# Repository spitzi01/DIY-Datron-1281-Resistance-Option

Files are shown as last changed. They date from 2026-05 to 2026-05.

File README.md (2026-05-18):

# DIY-Datron-1281-Resistance-Option
Add resistance measurement capabilities to your Datron 1281

I also replicated the resistance measurement board as closely as I could. This was a lot harder than the current board. Most of the parts are still avaiable. The CLA3106 ASIC can be replaced with my CPLD replacement. For other unavaiable components I tried to find alternatives. The precision resistors are the most expensive part of this project, but there is no real other choice than Vishay foil resistors and there are quite a few. There are also two resistance standards on this PCB. These are importeant for the selftest and the selfcal capability of this meter. For this purpose I ordered VHP resistors. The resistors for the current ranges are mostly custom ordered from Texas Components. The PCB features full mechanical compatibility to the original board and all guard traces.

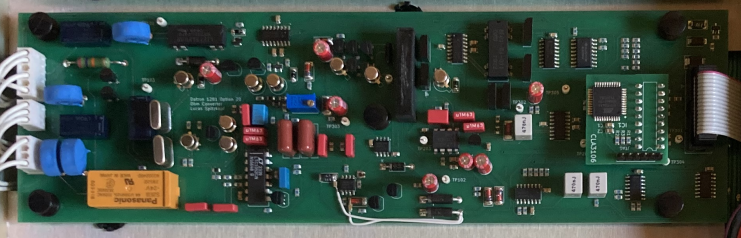
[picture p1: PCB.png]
DIY Resistance Option in Datron 1281


A full characterization of the resistance option was not possible due to not having access the known standard resistors. I did a comparative measurement in the 10kOhm range with a short against my Solartron 7081. The noise is definitly comparable to the Solartron meter. At the moment I will see this as a win until I am able to perform better measurements.

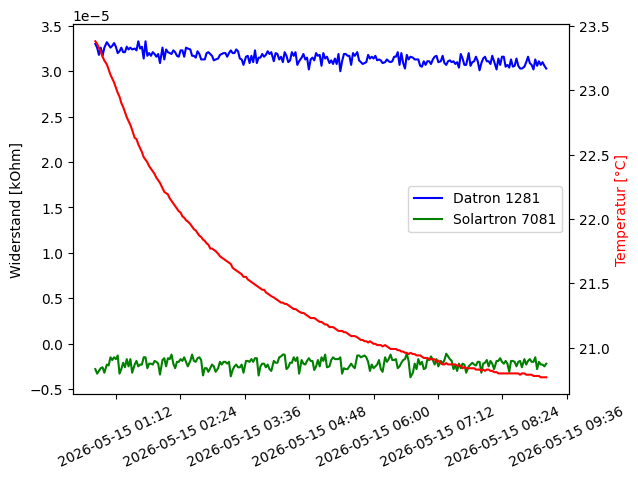
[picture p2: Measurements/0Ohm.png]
Noise and stability of the 10kOhm range


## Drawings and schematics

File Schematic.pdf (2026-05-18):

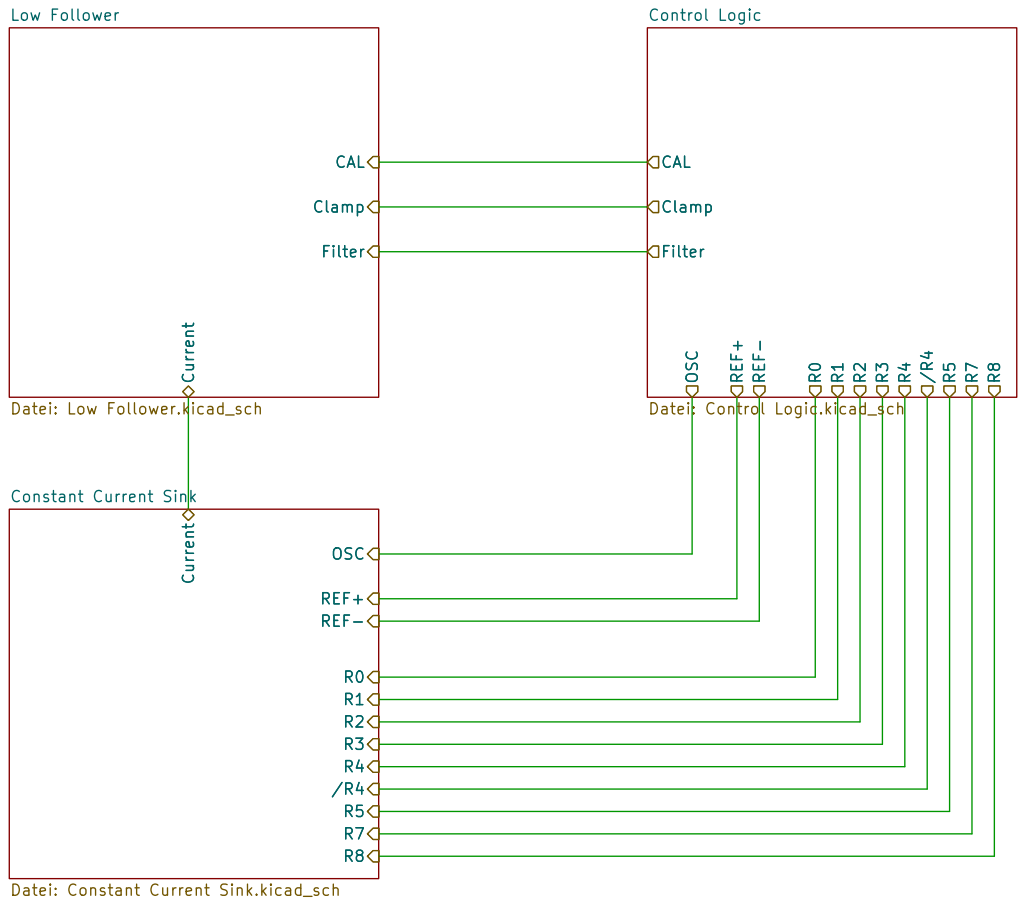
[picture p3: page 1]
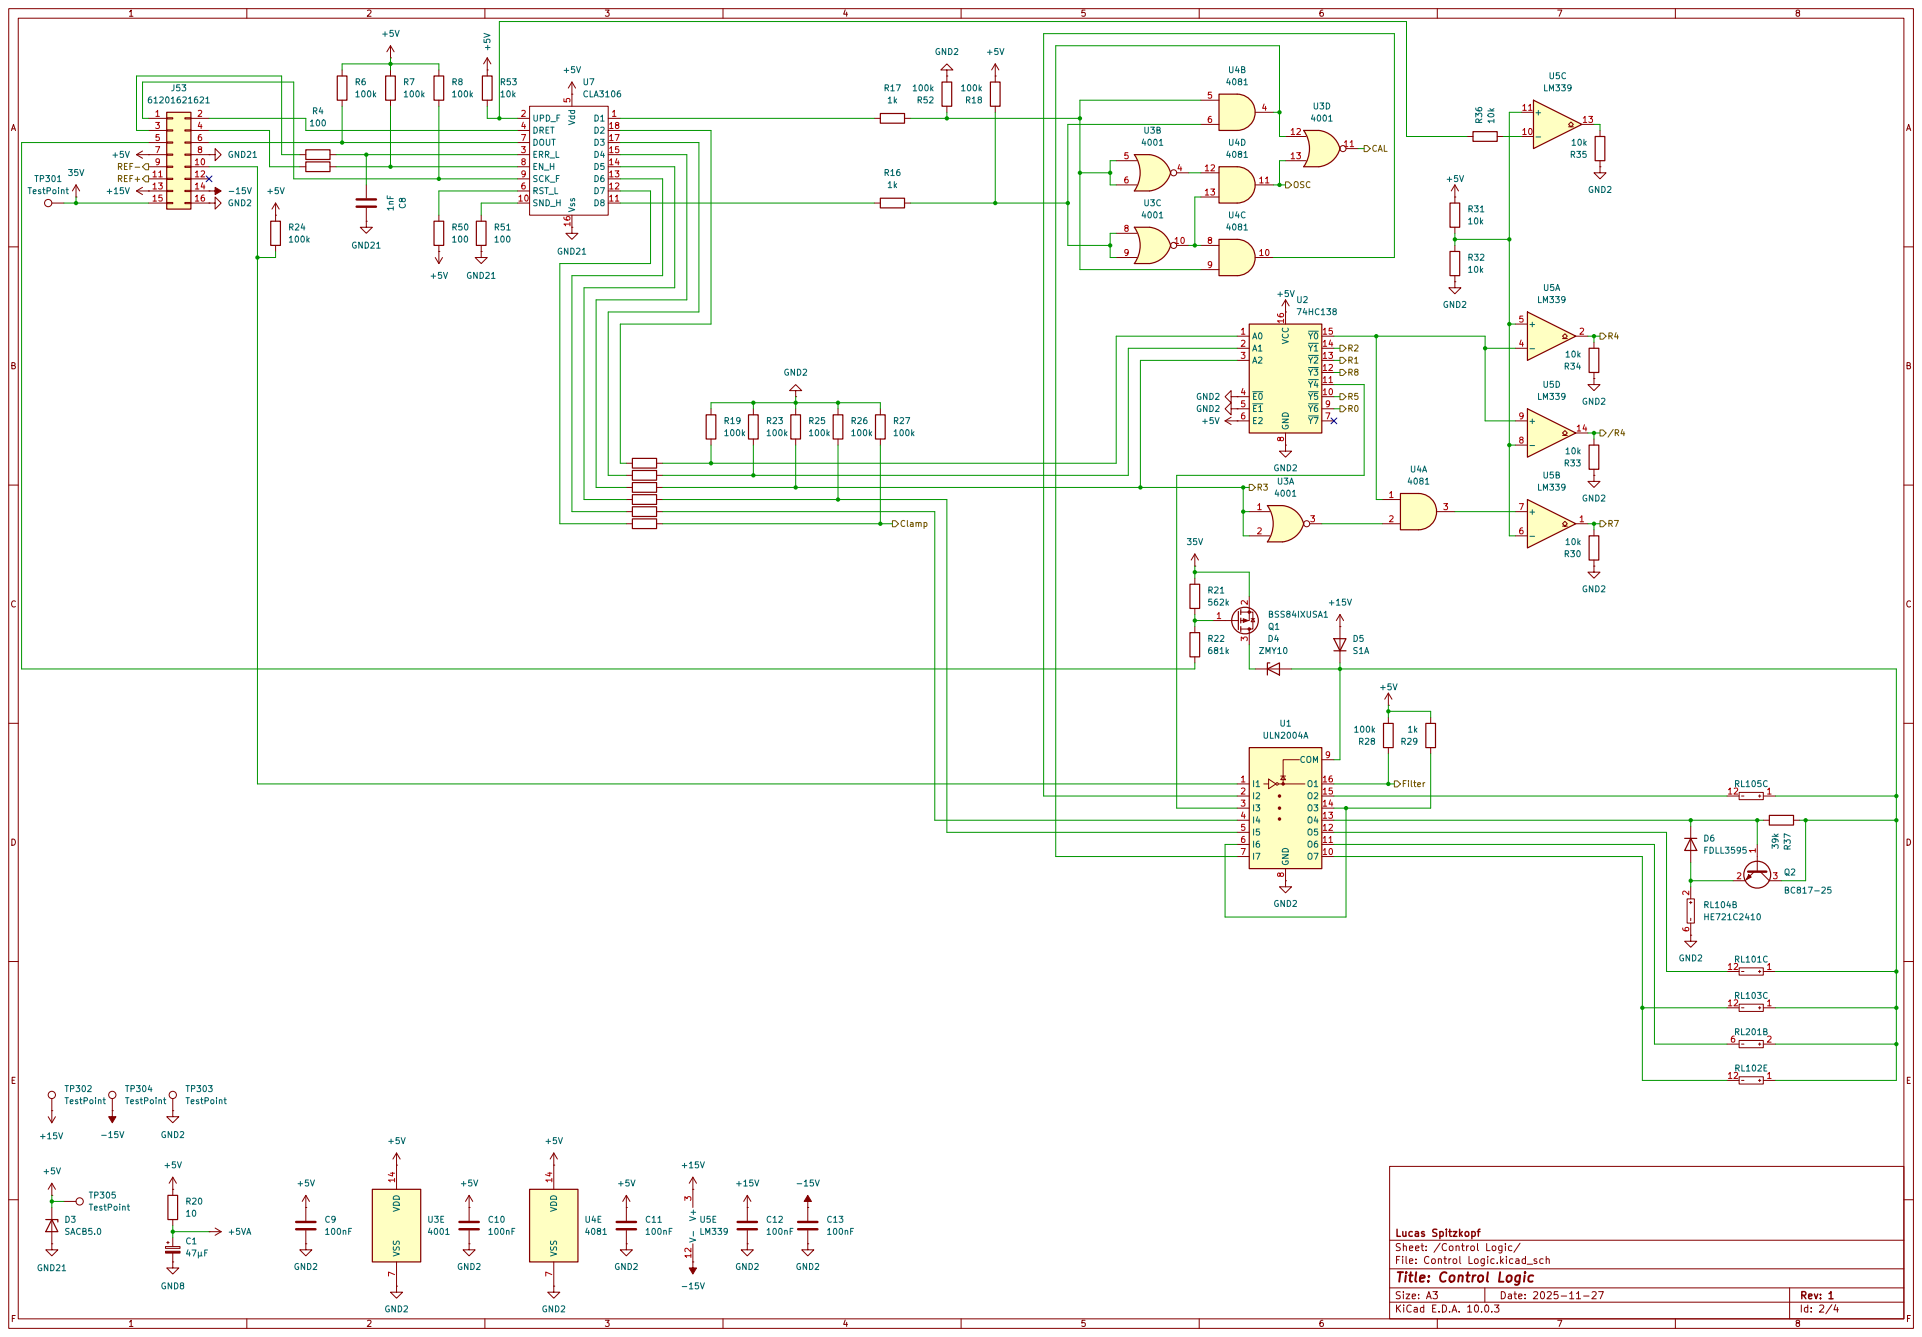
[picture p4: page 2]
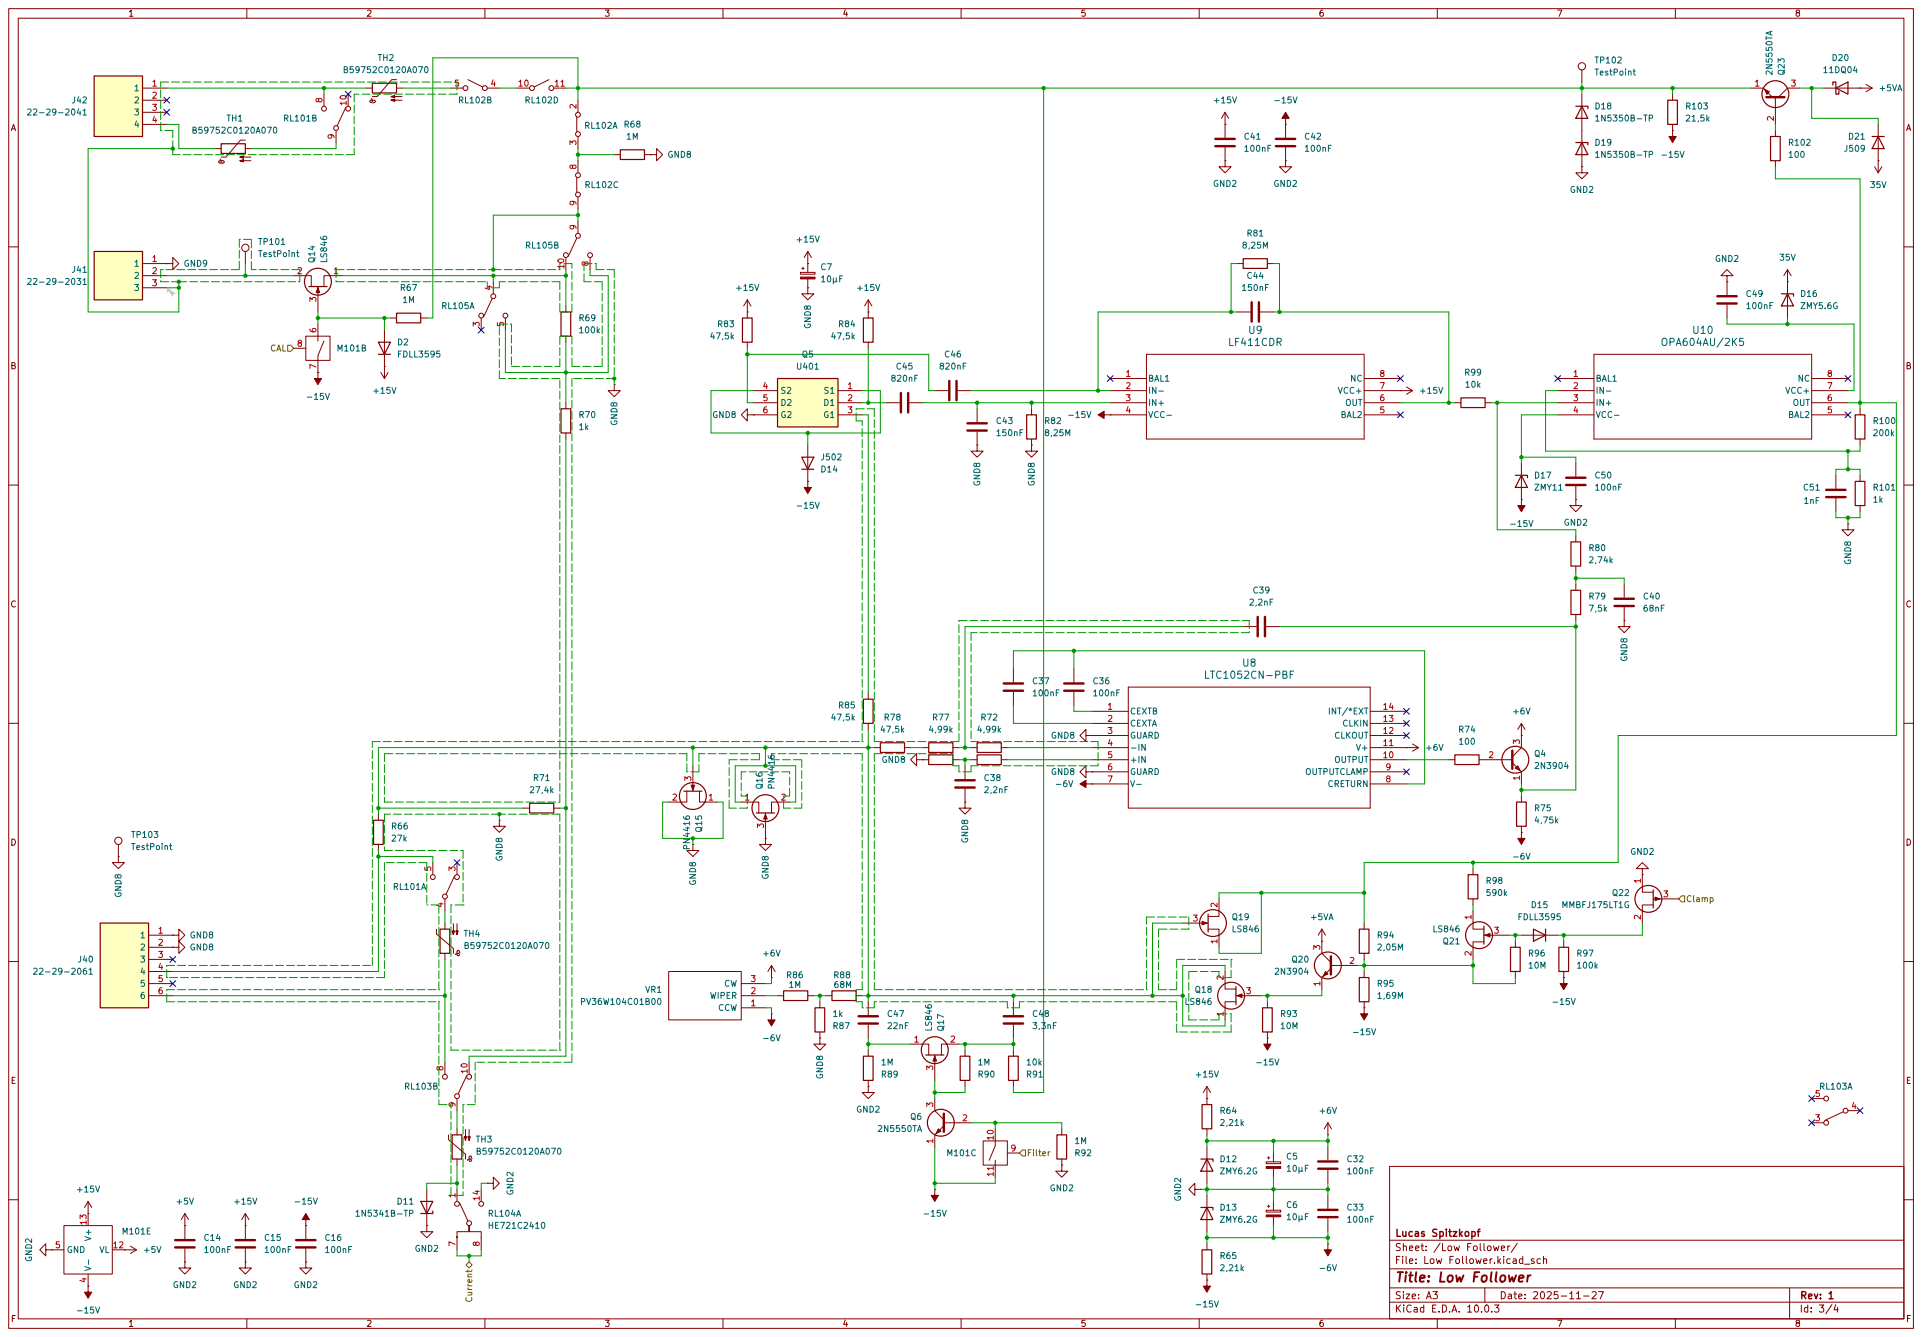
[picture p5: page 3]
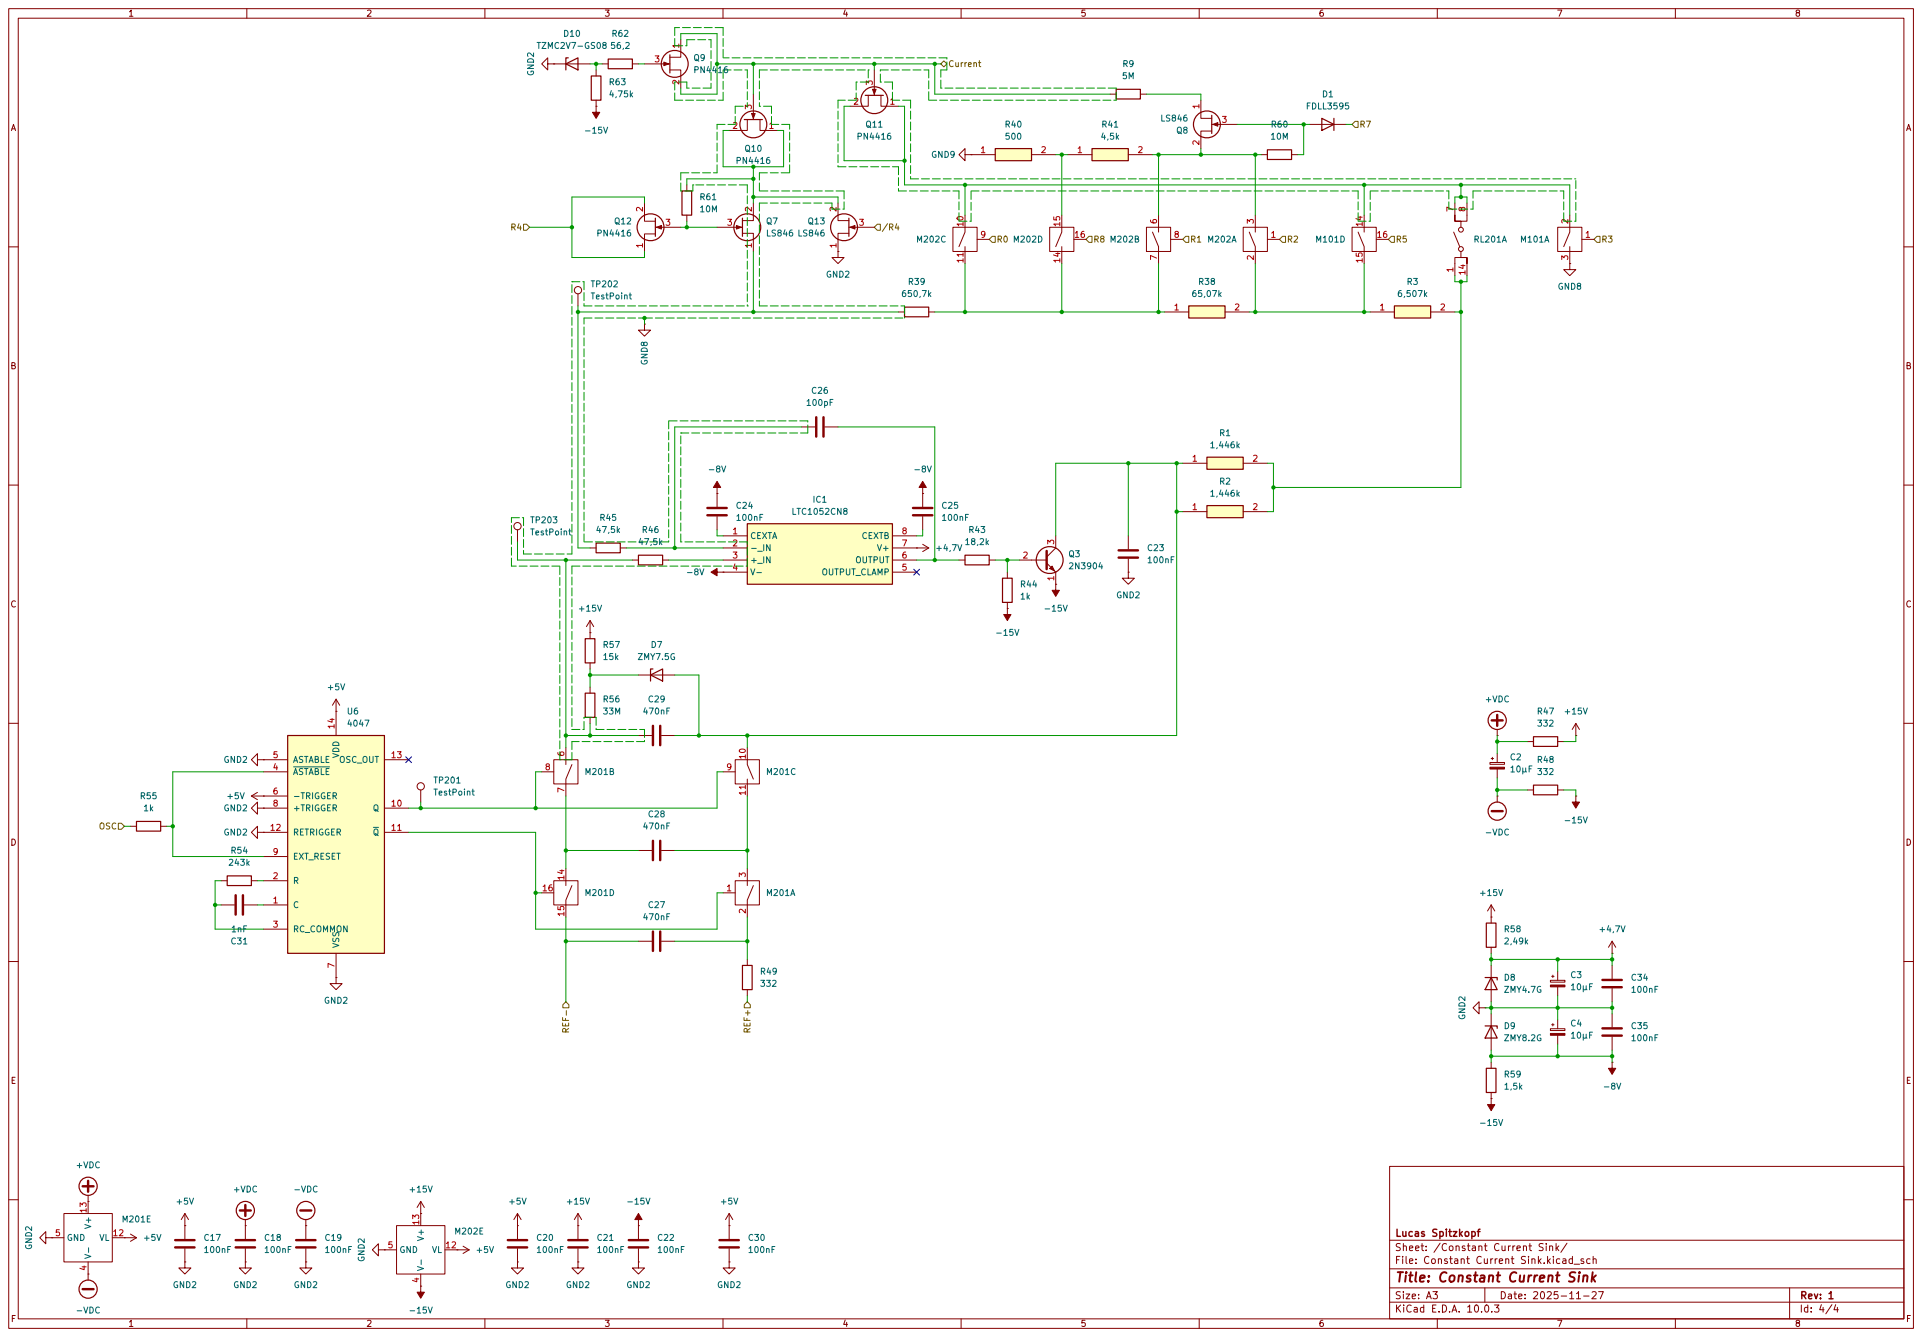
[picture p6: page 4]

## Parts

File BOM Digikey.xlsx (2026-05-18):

Digi-Key: Warenkorb
Index | Menge | Teilenummer | Hersteller-Teilenummer | Beschreibung | Kundenreferenz | Verfügbar | Lieferrückstände | Stückpreis | Gesamtpreis EUR
1 | 3 | 399-13064-ND | SMR5474J63J05L16.5CBULK | CAP FILM 0.47UF 5% 63VDC RADIAL |  | 3 | 0 | 2.42 | 7.26
2 | 3 | 255-1033-5-ND | TX2-24V | RELAY TELECOM DPDT 2A 24V |  | 0 | 3 | 2.65 | 7.95
3 | 1 | 306-1028-ND | 8L01-24-011 | RELAY REED SPST 500MA 24V |  | 1 | 0 | 4.16 | 4.16
4 | 1 | HE117-ND | HE721C2410 | RELAY REED SPDT 250MA 24V |  | 1 | 0 | 5.4 | 5.40
5 | 1 | 4878-ZMY10CT-ND | ZMY10 | DIODE ZENER 10V 1.3W DO213AB |  | 1 | 0 | 0.29 | 0.29
6 | 1 | SACB5.0CT-ND | SACB5.0 | TVS DIODE 5VWM 10VC SMB |  | 1 | 0 | 0.41 | 0.41
7 | 3 | DG211BDY-T1-E3CT-ND | DG211BDY-T1-E3 | IC SWITCH SPST-NCX4 85OHM 16SOIC |  | 3 | 0 | 2 | 6.00
8 | 1 | 296-ULN2004ANSRCT-ND | ULN2004ANSR | TRANS 7NPN DARL 50V 0.5A 16SO |  | 1 | 0 | 0.53 | 0.53
9 | 1 | WM2748-ND | 0022292061 | CONN HEADER VERT 6POS 2.54MM |  | 1 | 0 | 0.96 | 0.96
10 | 1 | WM2745-ND | 0022292031 | CONN HEADER VERT 3POS 2.54MM |  | 1 | 0 | 0.46 | 0.46
11 | 1 | WM2746-ND | 0022292041 | CONN HEADER VERT 4POS 2.54MM |  | 1 | 0 | 0.63 | 0.63
12 | 1 | 1655-S1ACT-ND | S1A | DIODE GEN PURP 50V 1A SMA |  | 1 | 0 | 0.11 | 0.11
13 | 1 | 732-2095-ND | 61201621621 | CONN HEADER VERT 16POS 2.54MM |  | 1 | 0 | 0.48 | 0.48
14 | 13 | 2019-RK73H2ATTD1001FCT-ND | RK73H2ATTD1001F | RES 1K OHM 1% 1/4W 0805 |  | 13 | 0 | 0.027 | 0.35
15 | 1 | 2019-RK73H2ATTD5623FCT-ND | RK73H2ATTD5623F | RES 562K OHM 1% 1/4W 0805 |  | 1 | 0 | 0.08 | 0.08
16 | 1 | 2019-RK73H2ATTD6813FCT-ND | RK73H2ATTD6813F | RES 681K OHM 1% 1/4W 0805 |  | 1 | 0 | 0.08 | 0.08
17 | 2 | 732-2103-ND | 61201623021 | CONN RCPT 16POS IDC 28AWG GOLD |  | 2 | 0 | 0.6 | 1.20
18 | 2 | WM2004-ND | 0022013067 | CONN RCPT HSG 6POS 2.54MM |  | 2 | 0 | 0.22 | 0.44
19 | 2 | 900-0022013037-ND | 0022013037 | CONN RCPT HSG 3POS 2.54MM |  | 2 | 0 | 0.12 | 0.24
20 | 2 | WM2002-ND | 0022013047 | CONN RCPT HSG 4POS 2.54MM |  | 2 | 0 | 0.14 | 0.28
21 | 18 | WM2625CT-ND | 0008500031 | CONN 22-30AWG CRIMP TIN |  | 18 | 0 | 0.064 | 1.15
22 | 10 | 2019-RK73H2ATTD1002FCT-ND | RK73H2ATTD1002F | RES 10K OHM 1% 1/4W 0805 |  | 10 | 0 | 0.027 | 0.27
23 | 1 | MC74HC138ADR2GOSCT-ND | MC74HC138ADR2G | IC DECODER/DEMUX 1 X 3:8 16-SOIC |  | 1 | 0 | 0.31 | 0.31
24 | 1 | MC14081BDR2GOSCT-ND | MC14081BDR2G | IC GATE AND 4CH 2-INP 14SOIC |  | 1 | 0 | 0.37 | 0.37
25 | 1 | MC14001BDR2GOSCT-ND | MC14001BDR2G | IC GATE NOR 4CH 2-INP 14SOIC |  | 1 | 0 | 0.36 | 0.36
26 | 1 | 296-LM339BIDRCT-ND | LM339BIDR | 36-V, -40C TO 85C QUAD STANDARD |  | 1 | 0 | 0.2 | 0.20
27 | 1 | BC817-25LT3GOSCT-ND | BC817-25LT3G | TRANS NPN 45V 0.5A SOT23-3 |  | 1 | 0 | 0.13 | 0.13
28 | 4 | FDLL3595CT-ND | FDLL3595 | DIODE STANDARD 125V 200MA SOD80 |  | 4 | 0 | 0.08 | 0.32
29 | 3 | 2N3904D26ZCT-ND | 2N3904TFR | TRANS NPN 40V 0.2A TO-92-3 |  | 3 | 0 | 0.08 | 0.24
30 | 1 | 296-31500-1-ND | CD4047BM96 | IC AMV 1-CIR 80-NS 14-SOIC |  | 1 | 0 | 0.58 | 0.58
31 | 5 | RPC1394-ND | SLG-2M-B | GROMMET SNAP LATCH BLACK |  | 5 | 0 | 0.234 | 1.17
32 | 5 | RPC1398-ND | SLPB-2M-B | SNAP LATCH BLACK 0.142" - 0.228" |  | 5 | 0 | 0.206 | 1.03
33 | 24 | 1276-6840-1-ND | CL21B104KCFNNNE | CAP CER 0.1UF 100V X7R 0805 |  | 24 | 0 | 0.033 | 0.80
34 | 6 | 2019-RK73H2ATTD1000FCT-ND | RK73H2ATTD1000F | RES 100 OHM 1% 1/4W 0805 |  | 6 | 0 | 0.08 | 0.48
35 | 13 | 2019-RK73H2ATTE1003FCT-ND | RK73H2ATTE1003F | RES 100K OHM 1% 1/4W 0805 |  | 13 | 0 | 0.029 | 0.38
36 | 1 | 255-1740-ND | S2EB-24V | RELAY GEN PURPOSE 4PST 4A 24V |  | 0 | 1 | 38.96 | 38.96
37 | 11 | 36-5002-ND | 5002 | PC TEST POINT MINIATURE WHITE |  | 11 | 0 | 0.19 | 2.09
38 | 1 | 4878-ZMY4.7GCT-ND | ZMY4.7G | DIODE ZENER 4.7V 1W DO213AB |  | 1 | 0 | 0.29 | 0.29
39 | 8 | 4004-LS846TO-724LROHS-ND | LS846 TO-72 4L ROHS | JFET N-CH 60V TO72-4 |  | 8 | 0 | 7.01 | 56.08
40 | 6 | 4004-PN4416TO-923LROHS-ND | PN4416 TO-92 3L ROHS | JFET N-CH 30V TO92 |  | 6 | 0 | 3.52 | 21.12
41 | 1 | 112-TZMC2V7-GS08CT-ND | TZMC2V7-GS08 | DIODE ZENER 2.7V 500MW SOD80 |  | 1 | 0 | 0.08 | 0.08
42 | 2 | 4878-ZMY6.2GCT-ND | ZMY6.2G | DIODE ZENER 6.2V 1W DO213AB |  | 2 | 0 | 0.29 | 0.58
43 | 4 | 495-76142-ND | B59752C0120A070 | SENSOR PTC 80OHM 25% DISC |  | 4 | 0 | 2.71 | 10.84
44 | 1 | 738-RSMF2JT27K0CT-ND | RSMF2JT27K0 | RES 27K OHM 5% 2W AXIAL |  | 1 | 0 | 0.14 | 0.14
45 | 1 | 4004-J502TO-922L-ND | J502 TO-92 2L | DIODE CUR REG 50V 516UA 350MW |  | 1 | 0 | 7.19 | 7.19
46 | 1 | 118-PV36W104C01B00-ND | PV36W104C01B00 | TRIMMER 100K OHM 0.5W PC PIN TOP |  | 1 | 0 | 1.3 | 1.30
47 | 2 | 2N5550TACT-ND | 2N5550TA | TRANS NPN 140V 0.6A TO-92-3 |  | 2 | 0 | 0.24 | 0.48
48 | 1 | MMBFJ175LT1GOSCT-ND | MMBFJ175LT1G | JFET P-CH 30V SOT23-3 |  | 1 | 0 | 0.43 | 0.43
49 | 1 | 296-46167-1-ND | OPA604AU/2K5 | IC OPAMP GP 1 CIRCUIT 8SOIC |  | 1 | 0 | 3.08 | 3.08
50 | 1 | 4878-ZMY8.2GCT-ND | ZMY8.2G | DIODE ZENER 8.2V 1W DO213AB |  | 1 | 0 | 0.29 | 0.29
51 | 1 | 4878-ZMY5.6GCT-ND | ZMY5.6G | DIODE ZENER 5.6V 1W DO213AB |  | 1 | 0 | 0.23 | 0.23
52 | 2 | 1N5350BGOS-ND | 1N5350BG | DIODE ZENER 13V 5W AXIAL |  | 2 | 0 | 0.63 | 1.26
53 | 1 | 4004-J509TO-922L-ND | J509 TO-92 2L | DIODE CUR REG 50V 3.6MA 350MW |  | 1 | 0 | 7.19 | 7.19
54 | 1 | 732-9460-1-ND | 860160372007 | CAP ALUM 47UF 20% 16V RADIAL TH |  | 1 | 0 | 0.12 | 0.12
55 | 6 | 732-9587-1-ND | 860160672009 | CAP ALUM 10UF 20% 50V RADIAL TH |  | 6 | 0 | 0.12 | 0.72
56 | 1 | 4878-ZMY7.5GCT-ND | ZMY7.5G | DIODE ZENER 7.5V 1W DO213AB |  | 1 | 0 | 0.3 | 0.30
57 | 1 | 1N5341BTPMSCT-ND | 1N5341B-TP | DIODE ZENER 6.2V 5W DO15 |  | 1 | 0 | 0.35 | 0.35
58 | 1 | 4878-ZMY11CT-ND | ZMY11 | DIODE ZENER 11V 1.3W DO213AB |  | 1 | 0 | 0.27 | 0.27
59 | 1 | 1655-11DQ04CT-ND | 11DQ04 | DIODE SCHOTTKY 40V 1.1A DO41 |  | 1 | 0 | 0.2 | 0.20
60 | 1 | 448-BSS84IXUSA1CT-ND | BSS84IXUSA1 | BSS84IXUSA1 |  | 1 | 0 | 0.2 | 0.20
61 | 1 | 296-46105-1-ND | LF411CDR | IC OPAMP JFET 1 CIRCUIT 8SOIC |  | 1 | 0 | 1.27 | 1.27
62 | 1 | 17-2485264-5-ND | 2485264-5 | DIP IC SOCKET 18P,SN |  | 1 | 0 | 1.1 | 1.10
63 | 3 | 1276-1169-1-ND | CL21B102KCANNNC | CAP CER 1000PF 100V X7R 0805 |  | 3 | 0 | 0.08 | 0.24
64 | 1 | 2019-RK73H2ATTD10R0FCT-ND | RK73H2ATTD10R0F | RES 10 OHM 1% 1/4W 0805 |  | 1 | 0 | 0.08 | 0.08
65 | 1 | 2019-RK73H2ATTD3902FCT-ND | RK73H2ATTD3902F | RES 39K OHM 1% 1/4W 0805 |  | 1 | 0 | 0.08 | 0.08
66 | 1 | 2019-RK73H2ATTD1822FCT-ND | RK73H2ATTD1822F | RES 18.2K OHM 1% 1/4W 0805 |  | 1 | 0 | 0.08 | 0.08
67 | 6 | 2019-RK73H2ATTD4752FCT-ND | RK73H2ATTD4752F | RES 47.5K OHM 1% 1/4W 0805 |  | 6 | 0 | 0.08 | 0.48
68 | 3 | 2019-RK73H2ATTD3320FCT-ND | RK73H2ATTD3320F | RES 332 OHM 1% 1/4W 0805 |  | 3 | 0 | 0.08 | 0.24
69 | 1 | 2019-RK73H2ATTD2433FCT-ND | RK73H2ATTD2433F | RES 243K OHM 1% 1/4W 0805 |  | 1 | 0 | 0.08 | 0.08
70 | 1 | 2019-RK73H2ATTD1502FCT-ND | RK73H2ATTD1502F | RES 15K OHM 1% 1/4W 0805 |  | 1 | 0 | 0.08 | 0.08
71 | 1 | 2019-RK73H2ATTD2491FCT-ND | RK73H2ATTD2491F | RES 2.49K OHM 1% 1/4W 0805 |  | 1 | 0 | 0.08 | 0.08
72 | 1 | 2019-RK73H2ATTD1501FCT-ND | RK73H2ATTD1501F | RES 1.5K OHM 1% 1/4W 0805 |  | 1 | 0 | 0.08 | 0.08
73 | 1 | 2019-RK73H2ATTD56R2FCT-ND | RK73H2ATTD56R2F | RES 56.2 OHM 1% 1/4W 0805 |  | 1 | 0 | 0.08 | 0.08
74 | 2 | 2019-RK73H2ATTD4751FCT-ND | RK73H2ATTD4751F | RES 4.75K OHM 1% 1/4W 0805 |  | 2 | 0 | 0.08 | 0.16
75 | 2 | 2019-RK73H2ATTD2211FCT-ND | RK73H2ATTD2211F | RES 2.21K OHM 1% 1/4W 0805 |  | 2 | 0 | 0.08 | 0.16
76 | 6 | 2019-RK73H2ATTD1004FCT-ND | RK73H2ATTD1004F | RES 1M OHM 1% 1/4W 0805 |  | 6 | 0 | 0.08 | 0.48
77 | 1 | 2019-RK73H2ATTD2742FCT-ND | RK73H2ATTD2742F | RES 27.4K OHM 1% 1/4W 0805 |  | 1 | 0 | 0.08 | 0.08
78 | 4 | 2019-RK73H2ATTD4991FCT-ND | RK73H2ATTD4991F | RES 4.99K OHM 1% 1/4W 0805 |  | 4 | 0 | 0.08 | 0.32
79 | 1 | 2019-RK73H2ATTD7501FCT-ND | RK73H2ATTD7501F | RES 7.5K OHM 1% 1/4W 0805 |  | 1 | 0 | 0.08 | 0.08
80 | 1 | 2019-RK73H2ATTD2741FCT-ND | RK73H2ATTD2741F | RES 2.74K OHM 1% 1/4W 0805 |  | 1 | 0 | 0.08 | 0.08
81 | 1 | 541-590KCCT-ND | CRCW0805590KFKEA | RES SMD 590K OHM 1% 1/4W 0805 |  | 1 | 0 | 0.08 | 0.08
82 | 1 | 2019-RK73H2ATTD2003FCT-ND | RK73H2ATTD2003F | RES 200K OHM 1% 1/4W 0805 |  | 1 | 0 | 0.08 | 0.08
83 | 1 | 2019-RK73H2ATTD2152FCT-ND | RK73H2ATTD2152F | RES 21.5K OHM 1% 1/4W 0805 |  | 1 | 0 | 0.08 | 0.08
84 | 1 | 2019-HV732ATTD336JCT-ND | HV732ATTD336J | RES 33M OHM 5% 1/4W 0805 |  | 1 | 0 | 0.31 | 0.31
85 | 4 | 2019-HV732ATTD1005FCT-ND | HV732ATTD1005F | RES 10M OHM 1% 1/4W 0805 |  | 4 | 0 | 0.34 | 1.36
86 | 2 | 2019-RK73H2ATTD8254FCT-ND | RK73H2ATTD8254F | RES 8.25M OHM 1% 1/4W 0805 |  | 2 | 0 | 0.08 | 0.16
87 | 1 | 541-CRCW080568M0JPEAHRCT-ND | CRCW080568M0JPEAHR | RES SMD 68M OHM 5% 1/4W 0805 |  | 1 | 0 | 0.32 | 0.32
88 | 1 | 541-CRCW08052M05FKEACT-ND | CRCW08052M05FKEA | RES SMD 2.05M OHM 1% 1/4W 0805 |  | 1 | 0 | 0.08 | 0.08
89 | 1 | 2019-RK73H2ATTD1694FCT-ND | RK73H2ATTD1694F | RES 1.69M OHM 1% 1/4W 0805 |  | 1 | 0 | 0.08 | 0.08
90 | 1 | 804-TLCX5M0000A-ND | TLCX5M0000A | RES 5M OHM 0.05% 1/4W RADIAL |  | 1 | 0 | 38.79 | 38.79
91 | 1 | 4004-U401TO-716LROHS-ND | U401 TO-71 6L ROHS | JFET 2N-CH 50V TO71 |  | 1 | 0 | 8.76 | 8.76
92 | 1 | LTC1052CN8#PBF-ND | LTC1052CN8#PBF | IC OPAMP ZERO-DRIFT 1 CIRC 8DIP |  | 1 | 0 | 8.45 | 8.45
93 | 1 | LTC1052CN#PBF-ND | LTC1052CN#PBF | IC OPAMP ZERO-DRIFT 1 CIRC 14DIP |  | 1 | 0 | 9.09 | 9.09
94 | 4 | 1928-MKS2C031001A00MC00CT-ND | MKS2C031001A00MC00 | CAP FILM 0.1UF 20% 63VDC RADIAL |  | 4 | 0 | 0.48 | 1.92
95 | 1 | 1928-FKP2D001001D00JSSD-ND | FKP2D001001D00JSSD | FKP 2 100 PF 100 VDC 4.5X6X7.2 P |  | 1 | 0 | 0.46 | 0.46
96 | 2 | P14634-ND | ECQ-E1824JF | CAP FILM 0.82UF 5% 100VDC RADIAL |  | 2 | 0 | 0.6 | 1.20
97 | 2 | 1928-1639-ND | MKS2C031501A00KSSD | CAP FILM 0.15UF 10% 63VDC RADIAL |  | 2 | 0 | 0.47 | 0.94
98 | 2 | 1928-1355-ND | FKS2D012201A00MSSD | CAP FILM 2200PF 20% 100VDC RAD |  | 2 | 0 | 0.42 | 0.84
99 | 1 | 1928-1635-ND | MKS2C022201A00KSSD | CAP FILM 0.022UF 10% 63VDC RAD |  | 1 | 0 | 0.46 | 0.46
100 | 1 | 399-PFR5332J63J11L4BULK-ND | PFR5332J63J11L4BULK | CAP FILM RAD |  | 1 | 0 | 1.15 | 1.15
101 | 1 | 495-2580-ND | B32529C0683K000 | CAP FILM 0.068UF 10% 63VDC RAD |  | 1 | 0 | 0.23 | 0.23

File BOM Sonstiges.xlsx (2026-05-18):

Cable
5m | PTFE Cable 1x AWG20
10cm | Flat IDC Cable 16 Poles
Precision Resistors
2x | Z201 | 1,446 kOhm | 0.05% | 0,2 ppm/°C
1x | Z201 | 6,507 kOhm | 0.05% | 0,2 ppm/°C
1x | Z201 | 65,07 kOhm | 0.05% | 0,2 ppm/°C
1x | Z206 | 650,7 kOhm | 0.05% | 0,2 ppm/°C
1x | Z201 | 4,5 kOhm | 0.05% | 0,2 ppm/°C
1x | Z201 | 500 Ohm | 0.05% | 0,2 ppm/°C
1x | VHP202Z | 1 kOhm | 0.01% | 0,2 ppm/°C
1x | VHP202Z | 100 kOhm | 0.01% | 0,2 ppm/°C
